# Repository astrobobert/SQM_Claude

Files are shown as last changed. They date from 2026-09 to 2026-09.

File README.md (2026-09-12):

# SQM_Claude — DIY Sky Quality Meter

MicroPython firmware for a WiFi-enabled Sky Quality Meter built on the
**Raspberry Pi Pico W** (RP2040) or **Pico W2** (RP2350) with an **Adafruit TSL2591** light sensor.

Serves readings over TCP using the Unihedron SQM-LE ASCII protocol, so it works
out of the box with astronomy software like APT, SQM Reader, and Sky Quality Monitor.

Based on:
- [PiSQM by chvvkumar](https://github.com/chvvkumar/PiSQM)
- ["Measuring Sky Brightness with a Raspberry Pi", MNASSA Oct 2017](https://www.mnassa.org.za/html/Oct2017/2017MNASSA..76..Oct..215.pdf)

Protocol reference: [Unihedron SQM-LE product page and user manual](https://unihedron.com/projects/sqm-le/).

---

## Hardware

| Component | Detail |
|---|---|
| Controller | Raspberry Pi Pico W (RP2040) or Pico W2 (RP2350) |
| Light sensor | Adafruit TSL2591 (I²C address `0x29`) |
| Temperature sensor | TMP117 breakout board (I²C address `0x48`, shares bus with TSL2591) |
| SDA | GPIO 16 (pin 21) |
| SCL | GPIO 17 (pin 22) |
| Sensor VIN | Pico 3V3(OUT) — pin 36 |
| Sensor GND | Pico GND — pin 33 |

### TMP117 wiring — pinned to the TSL2591

The two sensor breakouts are stacked and soldered together into one unit with header
pins, and only that unit is wired back to the Pico. The TMP117 sits **directly under
the TSL2591** with the mounting holes of the two boards aligned and the TMP117's
connector touching the underside of the TSL2591 PCB. The TMP117 header is soldered
**offset** by one or more positions so that its GND, SCL and SDA pins land on the
matching TSL2591 pads; the pins then bridge the two boards directly with no wires
between them.

| TMP117 pin | Lands on TSL2591 | Notes |
|---|---|---|
| GND | `GND` | |
| SCL | `SCL` | Same bus, GP17 at the Pico |
| SDA | `SDA` | Same bus, GP16 at the Pico |
| V+ / VCC | `VIN` | 3V3 from the Pico, passed through |
| ADD0 | GND | Selects address `0x48` (`TMP117_ADDR` in `lib/settings.py`) |

**Cut the power-LED trace on both boards** before assembly. The TSL2591 and TMP117
breakouts each carry a green power LED that sits a few millimetres from the light
sensor and would otherwise add a constant glow inside the sensor bay. Each board has
a small jumper trace next to the LED for exactly this purpose; sever it with a
hobby knife and confirm the LED stays dark on power-up.

Four pigtail wires (3V3, GND, SDA, SCL) are soldered to the header pins and run to
the Pico. Everything is soldered directly — no JST-XH or other plug-in connectors —
with heat-shrink over each joint so bare wire cannot touch a neighbouring pad when
the lid is closed. Connectors were dropped because they add height in the sensor
bay and can work loose with temperature cycling outdoors.

Leave the TSL2591 `INT` pad and the TMP117 `ALERT` pad unconnected — the firmware
polls both sensors. The TSL2591 breakout already has I²C pull-ups, and the TMP117
breakout adds its own, which is fine at 400 kHz over a few centimetres. If your
TMP117 breakout has an address jumper instead of a bare ADD0 pin, set it for `0x48`
or change `TMP117_ADDR` to match (`0x48`–`0x4B`).

The stacked mounting matters: with the TMP117 pressed against the underside of the
TSL2591 board it tracks the light sensor's own temperature rather than the air in
the enclosure, which is what the `C` field in the SQM-LE response is meant to
report. Do not mount it beside the TSL2591 or elsewhere in the bay.

---

## Chassis

The `chassis/` folder contains a three-part 3D-printable enclosure. The parts are
lettered in stacking order from the top down; the footprint is about 87 × 54 mm.

| File | Part | Size (mm) | Holds |
|---|---|---|---|
| `A_Hood.stl` | Hood | 48 × 48 × 9 | Sits over the aperture on the lid and shields the TSL2591 from stray side light |
| `B_Lid.stl` | Lid | 87 × 54 × 18 | Carries everything: the stacked TSL2591 / TMP117 sensor unit under the aperture and the Pico W / W2 underneath |
| `C_Pan.stl` | Pan | 87 × 54 × 10 | Bottom cover; screws to the lid and sticks to the power bank |

The model is designed for **2 mm screw inserts**.

**Assembly sequence:**

1. Cut the power-LED trace on the TSL2591 and on the TMP117 (see [Hardware](#hardware)).
2. Stack the TMP117 directly under the TSL2591 with the mounting holes aligned and
   the TMP117 connector touching the underside of the TSL2591 PCB. Solder the boards
   together with header pins, offsetting the TMP117 header so its GND, SCL and SDA
   pins land on the matching TSL2591 pads.
3. Solder four pigtails (3V3, GND, SDA, SCL) to the header pins and heat-shrink the joints.
4. Fit the sensor unit into the lid with the TSL2591 directly under the aperture, sensor
   facing up, passing the pigtails through the access hole.
5. Solder the pigtails to the Pico (3V3 OUT, GND, GP16, GP17), and
   mount the Pico to the underside of the lid.
6. Screw the lid to the pan, then screw the hood to the lid over the aperture.
7. Stick the finished unit to a USB power bank with double-sided tape.

The hood is a separate part so it can be reprinted taller or with a different
opening without reprinting the lid.

---

## Project Structure

```
SQM_Claude/
├── main.py              entry point (imports src/SQM_Claude)
├── src/
│   └── sqm_claude.py    WiFi connect + SQM-LE / HTTP servers + SQM logic
├── www/
│   └── index.html       browser page served by the meter at http://<ip>/
├── lib/
│   ├── tsl2591.py           TSL2591 MicroPython driver
│   ├── tmp117.py            TMP117 MicroPython driver
│   ├── settings.py          I²C pins, gain, calibration, port
│   ├── secrets.py           WiFi credentials (not committed)
│   └── secrets.example.py  credential template
├── chassis/
│   ├── A_Hood.stl       stray-light hood over the aperture
│   ├── B_Lid.stl        lid carrying the sensor unit and the Pico
│   └── C_Pan.stl        bottom cover
├── tools/
│   └── sqm_console.py   desktop web console for rx / cx (stdlib only)
├── requirements.txt
└── LICENSE
```

---

## Deployment

Code runs on **MicroPython** — not CPython.

### 1. Flash MicroPython

Download the `.uf2` for your board from [micropython.org/download](https://micropython.org/download/).
Hold BOOTSEL while plugging in the Pico, copy the `.uf2` to the Pico drive, and it will reboot automatically.

### 2. Create WiFi credentials

`lib/secrets.py` is git-ignored. Copy the example and fill in your details:

```bash
cp lib/secrets.example.py lib/secrets.py
```

```python
WIFI_NETWORKS = [
    ("your_network_name",  "your_wifi_password"),
    ("phone_hotspot_name", "your_hotspot_password"),
]
```

List as many networks as you like — home, an observing site, a phone hotspot. On boot
the meter scans and joins the first network in this list that is in range, so put your
preferred one first. Hidden SSIDs are tried after the visible ones.

### 3. Upload the project

**Option A — MicroPico VS Code extension**

Open `SQM_Claude/` in VS Code with the MicroPico extension installed, then use
**"Upload project to Pico"** to sync all files. The Pico boots `main.py` automatically on power-up.

**Option B — mpremote**

```bash
pip install mpremote
mpremote cp lib/tsl2591.py     :/lib/tsl2591.py
mpremote cp lib/tmp117.py      :/lib/tmp117.py
mpremote cp lib/secrets.py     :/lib/secrets.py
mpremote cp lib/settings.py    :/lib/settings.py
mpremote cp src/sqm_claude.py  :/src/sqm_claude.py
mpremote mkdir :/www
mpremote cp www/index.html     :/www/index.html
mpremote cp main.py            :/main.py
```

Quick test without rebooting:

```bash
mpremote run src/sqm_claude.py
```

---

## Configuration

Edit `lib/settings.py` before uploading:

| Setting | Default | Notes |
|---|---|---|
| `I2C_SDA_PIN` | `16` | GPIO for SDA |
| `I2C_SCL_PIN` | `17` | GPIO for SCL |
| `TSL2591_GAIN` | `"MAX"` | `LOW` / `MED` / `HIGH` / `MAX` |
| `TSL2591_INTEGRATION` | `"600MS"` | `100MS` – `600MS` |
| `TMP117_ADDR` | `0x48` | I²C address (ADD0 to GND = `0x48`; range `0x48`–`0x4B`) |
| `CALIBRATION_OFFSET` | `12.6` | mag/arcsec² zero-point — adjust to match a reference meter |
| `TCP_PORT` | `10001` | Standard Unihedron SQM port |

---

## TCP Protocol (Unihedron SQM-LE compatible)

Connect to the Pico's IP on port **10001**. The device accepts one connection at a time (per the SQM-LE spec).

```bash
telnet <pico-ip> 10001
# or
nc <pico-ip> 10001
```

### Commands

| Command | Effect |
|---|---|
| `rx` | Take a reading; return one SQM-LE formatted line and close |
| `cx` | Enter calibration mode (persistent connection, 60 s timeout) |
| `cx <value>` | Set `CALIBRATION_OFFSET` to `value` and persist to `lib/settings.py` |
| `cx exit` | Exit calibration mode and close connection |

### SQM-LE response format

The `rx` response follows the [Unihedron SQM-LE ASCII protocol](https://unihedron.com/projects/sqm-le/) (§8.2.1 of the user manual):

```
r, XX.XXm,0000000000Hz,0000000000c,0000000.000s,  27.4C\r\n
```

| Field | Example | Meaning |
|---|---|---|
| MPSAS | `21.45m` | Sky brightness (mag/arcsec²) |
| Hz | `0000005915Hz` | Derived from lux × 50 000 (TSL2591 is not a photon counter) |
| Counts | `0000000042c` | Raw TSL2591 channel-0 ADC value |
| Period | `0000000.000s` | Counts / 460 800 Hz (SQM-LE convention) |
| Temp | `27.4C` | TMP117 sensor temperature (°C) |

Astronomy software parses columns by fixed position — do not change field widths.

**APT note:** APT connects and immediately sends `rx`, expecting only the SQM-LE string back. The device handles this correctly.

---

## Web Page and JSON API (port 80)

The meter also serves a page from its own flash, so any phone, tablet or laptop on the
same WiFi can open it with nothing installed. The boot log prints the address:

```
http://<pico-ip>/
```

No need to know the IP: the meter answers multicast DNS as `sqm`, so this works from
Windows, macOS, Linux and iOS on the same WiFi:

```
http://sqm.local/
```

Some Android browsers cannot resolve `.local` names. If the phone cannot open it, give
the meter a fixed address with a DHCP reservation in the router and bookmark that, or
read the address from the router's client list where the meter shows as `sqm`.

The page shows the live MPSAS, Bortle class, lux, temperature and raw counts, takes
single or auto-repeat readings, reads and sets the calibration offset (with a "Suggest"
button that works out the new offset from a reference meter reading), has a red
night-vision palette, and keeps a CSV-exportable log for the session.

The same data is available as JSON for scripts and home-automation tools:

| Route | Method | Returns |
|---|---|---|
| `/api/rx` | GET | `{"mpsas": 21.45, "bortle": 4, "lux": 0.00046, "hz": 23, "chan0": 6239, "chan1": 1425, "temp": 12.3, "offset": 12.6, "line": "r, 21.45m,..."}` |
| `/api/offset` | GET | `{"offset": 12.6}` |
| `/api/offset` | POST `{"value": 12.8}` | Sets and persists the offset, returns the new value |

`mpsas` and `bortle` are `null` when the sensor is below its noise floor. The HTTP
server shares the single-client loop with the SQM-LE port, so a request waits while
APT is being served, and vice versa.

---

## Physics

```
MPSAS = −2.5 × log₁₀(lux) + CALIBRATION_OFFSET
```

MPSAS is a logarithmic scale — higher values mean darker sky. Each magnitude step is ~2.5× in brightness.

**Bortle scale reference:**

| Bortle | Min MPSAS | Description |
|---|---|---|
| 1 | 21.99 | Excellent dark sky |
| 2 | 21.89 | Truly dark site |
| 3 | 21.69 | Rural sky |
| 4 | 20.49 | Rural/suburban transition |
| 5 | 19.50 | Suburban sky |
| 6 | 18.94 | Bright suburban sky |
| 7 | 18.38 | Suburban/urban transition |
| 8 | 17.83 | City sky |
| 9 | — | Inner-city sky |

Expected precision for a calibrated unit is **±0.10 mag/arcsec²**. This build is uncalibrated by default.

---

## Calibration Workflow

1. Connect via TCP.
2. Send `cx` to enter calibration mode.
3. Take a reading with a reference meter (or compare against a known Bortle-class site).
4. Send `cx <offset>` to update the zero-point, e.g. `cx 14.20`.
5. Verify with `rx`.
6. Send `cx exit` — the new offset is persisted to `lib/settings.py` on flash and survives reboots.

### Desktop console

`tools/sqm_console.py` wraps the steps above in a browser page. It runs on the
desktop, needs nothing beyond the Python standard library, and relays each
button press to the meter as one short TCP session:

```
python tools/sqm_console.py                    # meter at 192.168.0.252:10001
python tools/sqm_console.py --sqm 192.168.0.50 # different meter address
python tools/sqm_console.py --lan              # also serve to phones / laptops on the WiFi
```

With `--lan` the start-up banner prints a `http://<desktop-ip>:8080/` URL that any
device on the same WiFi can open. Allow Python through Windows Firewall on
private networks when prompted (or add an inbound rule for TCP 8080).

The page opens at http://127.0.0.1:8080/ and offers single or auto-repeat `rx`
readings, a `cx` panel that reads and writes the offset, a "Suggest" button
that computes the new offset from a reference meter reading, a night-vision
red palette, and a CSV log of the session.

---

## LED Status

| Pattern | Meaning |
|---|---|
| 3 slow blinks | Booting |
| Rapid blinking | Connecting to WiFi |
| 5 fast blinks | WiFi connected, server starting |
| Solid on | Server idle, waiting for client |
| 2 quick blinks then on | Client connected, reading taken |

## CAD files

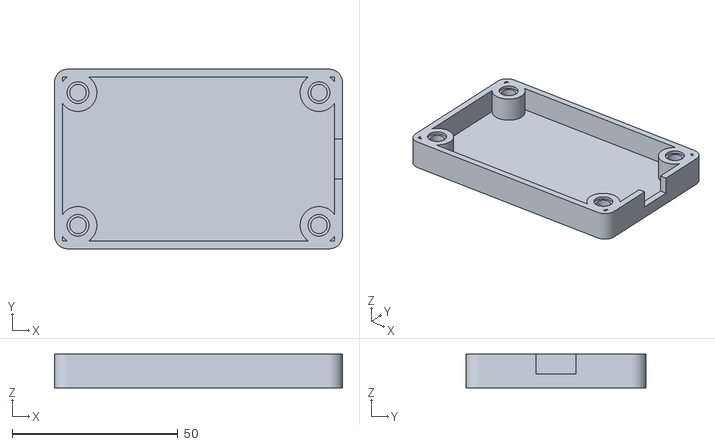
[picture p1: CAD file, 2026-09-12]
chassis/C_Pan.stl
87.0 x 54.3 x 10.2

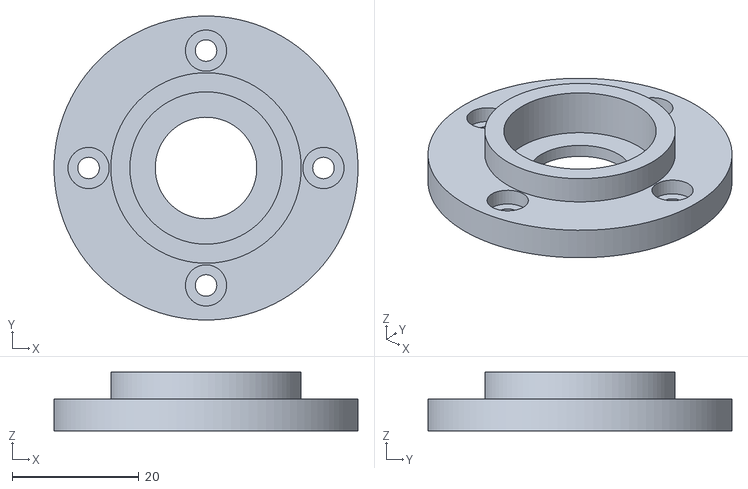
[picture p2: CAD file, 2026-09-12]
chassis/A_Hood.stl
47.9 x 47.9 x 9.23

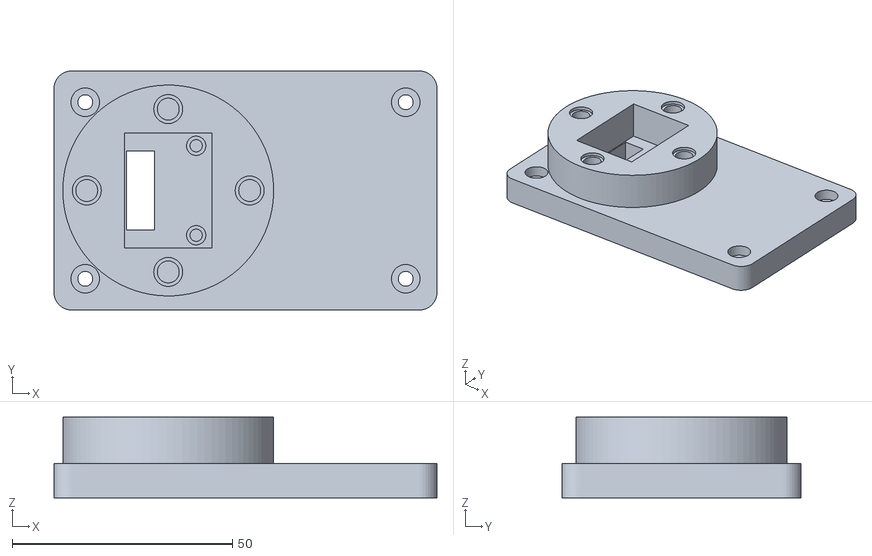
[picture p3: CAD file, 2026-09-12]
chassis/B_Lid.stl
87.0 x 54.3 x 18.3

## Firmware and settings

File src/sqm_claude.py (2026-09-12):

"""
Sky Quality Meter — Pico W2 + TSL2591
Connects to WiFi and serves Unihedron SQM-LE compatible readings over TCP,
plus a browser page and JSON API over HTTP.

SQM-LE: client connects to TCP_PORT, optionally sends "rx\n", receives:
  r, XX.XXm,0000000000Hz,NNNNNNNNNNN c,XXXXXXX.XXXlx,XXXXX.XC\r\n
HTTP:   http://<meter-ip>:HTTP_PORT/  serves /www/index.html; /api/rx and
        /api/offset expose the same readings and calibration as JSON.
"""

import json
import math
import os
import select
import socket
import time
import network
from machine import I2C, Pin

import sys
sys.path.insert(0, "/lib")

from tsl2591 import (
    TSL2591,
    GAIN_LOW, GAIN_MED, GAIN_HIGH, GAIN_MAX,
    INT_100MS, INT_200MS, INT_300MS, INT_400MS, INT_500MS, INT_600MS,
)
from tmp117 import TMP117
import secrets
from settings import (
    I2C_ID, I2C_SDA_PIN, I2C_SCL_PIN, I2C_FREQ,
    TSL2591_GAIN, TSL2591_INTEGRATION,
    CALIBRATION_OFFSET,
    TCP_PORT, TCP_TIMEOUT_S, CX_TIMEOUT_S,
    HTTP_PORT, HTTP_TIMEOUT_S, HOSTNAME,
    TMP117_ADDR,
    LED_PIN,
)

# ── Map config strings to driver constants ────────────────────────────────────
_GAIN_MAP = {
    "LOW": GAIN_LOW, "MED": GAIN_MED, "HIGH": GAIN_HIGH, "MAX": GAIN_MAX,
}
_INT_MAP = {
    "100MS": INT_100MS, "200MS": INT_200MS, "300MS": INT_300MS,
    "400MS": INT_400MS, "500MS": INT_500MS, "600MS": INT_600MS,
}


# ── LED helper ────────────────────────────────────────────────────────────────

def make_led():
    try:
        return Pin(LED_PIN, Pin.OUT)
    except Exception:
        return None


def blink(led, times: int = 1, on_ms: int = 100, off_ms: int = 100):
    if led is None:
        return
    for _ in range(times):
        led.on()
        time.sleep_ms(on_ms)
        led.off()
        time.sleep_ms(off_ms)


# ── WiFi ──────────────────────────────────────────────────────────────────────

def wifi_networks() -> list:
    """Credentials as [(ssid, password), ...]; accepts the old single-SSID form."""
    nets = getattr(secrets, "WIFI_NETWORKS", None)
    if nets:
        return list(nets)
    return [(secrets.WIFI_SSID, secrets.WIFI_PASSWORD)]


_STATUS_NAMES = {
    0: "IDLE", 1: "CONNECTING", 2: "NO_IP", 3: "GOT_IP",
    -1: "CONNECT_FAIL", -2: "NO_AP_FOUND", -3: "WRONG_PASSWORD",
}


def _status_name(status) -> str:
    return _STATUS_NAMES.get(status, "UNKNOWN")


def _visible_ssids(wlan) -> set:
    """SSIDs the radio can see. An empty set means "scan unavailable", not "none"."""
    try:
        return {n[0].decode() for n in wlan.scan() if n[0]}
    except Exception as e:
        print(f"[WIFI] scan failed: {e}")
        return set()


def _try_connect(wlan, ssid: str, password: str, led, timeout_s: int) -> bool:
    print(f"Connecting to {ssid} ", end="")
    wlan.connect(ssid, password)

    deadline = time.ticks_add(time.ticks_ms(), timeout_s * 1000)
    # The radio can briefly report a failure while the join is still in flight,
    # so a negative status is only believed once it has had time to settle.
    settled  = time.ticks_add(time.ticks_ms(), 3000)
    while not wlan.isconnected():
        status  = wlan.status()
        expired = time.ticks_diff(deadline, time.ticks_ms()) <= 0
        # A settled negative status is terminal (no such AP, bad password,
        # association refused), so move on instead of waiting out the timeout.
        rejected = status < 0 and time.ticks_diff(settled, time.ticks_ms()) <= 0
        if expired or rejected:
            why = f"failed after {timeout_s}s" if expired else "rejected"
            print(f"\n[WIFI] {ssid} {why} (status={status} {_status_name(status)})")
            try:
                wlan.disconnect()
            except Exception:
                pass
            return False
        blink(led, on_ms=50, off_ms=50)
        print(".", end="")
        time.sleep_ms(500)
    return True


def wifi_connect(networks, led=None, timeout_s: int = 30, passes: int = 2) -> network.WLAN:
    """Try each (ssid, password) in turn until one associates."""
    try:
        network.hostname(HOSTNAME)   # DHCP name, so http://sqm/ may work too
    except Exception as e:
        print(f"[WIFI] hostname not set: {e}")
    wlan = network.WLAN(network.STA_IF)
    wlan.active(True)
    time.sleep_ms(500)   # radio needs a moment before the first scan is complete

    if wlan.isconnected():
        print(f"Already connected — IP: {wlan.ifconfig()[0]}")
        return wlan

    for attempt in range(passes):
        visible = _visible_ssids(wlan)
        # Networks in range first, in the order secrets.py lists them; hidden
        # SSIDs never appear in a scan, so try the rest afterwards anyway.
        seen   = [n for n in networks if n[0] in visible]
        unseen = [n for n in networks if n[0] not in visible]
        for ssid, password in seen + unseen:
            if _try_connect(wlan, ssid, password, led, timeout_s):
                print(f"\nConnected to {ssid} — IP: {wlan.ifconfig()[0]}")
                return wlan
        if attempt + 1 < passes:
            print("[WIFI] no network joined — retrying")

    raise RuntimeError(f"WiFi failed: none of {[n[0] for n in networks]} joined")


# ── SQM maths ─────────────────────────────────────────────────────────────────

_MPSAS_MIN  = 16.0   # heavily light-polluted urban sky
_MPSAS_MAX  = 23.0   # natural airglow sets the physical dark-sky limit
_cal_offset = CALIBRATION_OFFSET   # mutable; updated by cx command


def lux_to_mpsas(lux: float) -> float:
    if lux <= 0:
        return 99.99  # sensor below noise floor
    mpsas = -2.5 * math.log10(lux) + _cal_offset
    return max(_MPSAS_MIN, min(_MPSAS_MAX, mpsas))


# Thresholds from Sky & Telescope / Globe at Night SQM correlation table.
# Each tuple is (minimum MPSAS for this class, Bortle class).
_BORTLE_THRESHOLDS = (
    (21.99, 1),
    (21.89, 2),
    (21.69, 3),
    (20.49, 4),
    (19.50, 5),
    (18.94, 6),
    (18.38, 7),
    (17.83, 8),
)

def mpsas_to_bortle(mpsas: float) -> int:
    for threshold, cls in _BORTLE_THRESHOLDS:
        if mpsas >= threshold:
            return cls
    return 9


def update_calibration(new_val: float):
    global _cal_offset
    _cal_offset = new_val
    path = "/lib/settings.py"
    with open(path) as f:
        lines = f.readlines()
    with open(path, "w") as f:
        for line in lines:
            if line.startswith("CALIBRATION_OFFSET"):
                f.write(f"CALIBRATION_OFFSET = {new_val}\n")
            else:
                f.write(line)


# ── Unihedron SQM-LE response formatter ──────────────────────────────────────
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

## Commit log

2026-05-10 Initial commit — SQM_Claude DIY Sky Quality Meter
    [SQM Chassis Bottom.stl, SQM Chassis Top.stl]
2026-09-12 Add HTTP web UI, TMP117 sensor, multi-network WiFi, and V2 chassis
    - Serve a browser page and JSON API on port 80 alongside the SQM-LE
    TCP protocol on port 10001 (www/index.html, /api/rx, /api/offset)
    - Add TMP117 temperature driver and report die temperature in readings
    - WiFi connect now scans and tries a list of networks in order,
    retrying hidden SSIDs after visible ones
    - Add tools/sqm_console.py desktop relay console for rx/cx commands
    - Replace chassis STLs with the three-part Hood / Lid / Pan design
    - Update README and CLAUDE.md for the new features and deploy steps
    [A_Hood.stl, B_Lid.stl, C_Pan.stl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]
2026-09-12 README: document three-part chassis and TMP117 piggy-back wiring
    - Replace the old Top/Bottom chassis table with A_Hood / B_Lid / C_Pan,
    including part sizes, stacking order and assembly notes
    - Add a TMP117 wiring table showing it fed from the TSL2591 header pads,
    mounted offset beside the light sensor, with ADD0 to GND for 0x48
    - Update the project structure tree to match chassis/
2026-09-12 README: note sensor wiring is soldered with heat-shrink, no JST-XH connectors
2026-09-12 README: correct assembly sequence and board-to-board TMP117 wiring
    - TMP117 is pinned to the TSL2591 with an offset header so GND/SCL/SDA
    land on the matching pads; pigtails from the header pins go to the Pico
    - Add step to cut the power-LED trace on both breakouts
    - Pico mounts to the underside of the lid, not the pan; pan is the
    bottom cover and the unit is taped to a power bank
    - Replace assembly notes with the numbered build sequence
2026-09-12 README: TMP117 is stacked directly under the TSL2591, not beside it
    Mounting holes aligned, TMP117 connector touching the underside of the
    TSL2591 PCB, so it reads the light sensor board temperature.
